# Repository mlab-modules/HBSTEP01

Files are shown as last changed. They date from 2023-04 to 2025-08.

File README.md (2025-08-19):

# HBSTEP01 - Stepper motor driver

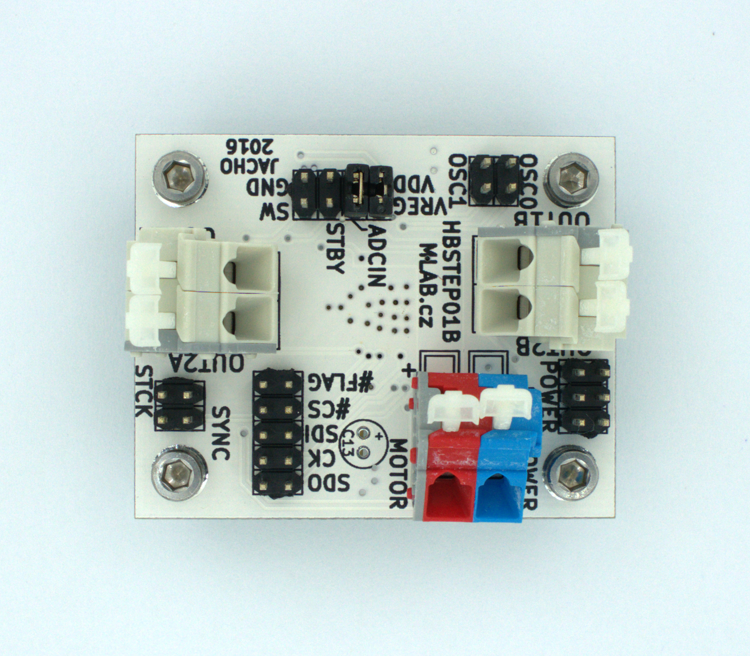
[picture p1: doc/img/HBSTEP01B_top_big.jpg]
HBSTEP01B


The HBSTEP01 is a bipolar stepper motor driver module built around the STMicroelectronics L6470 chip. It provides a complete microstepping motor control solution with SPI interface, allowing for precise motor control and advanced motion features.

## Features

* Microstepping up to 1/128 steps
* Operating voltage: 8 V to 45 V
* Maximum output current: 3 A RMS (7 A peak)
* Integrated non-dissipative current sensing
* Programmable speed profiles and position control
* Sensorless stall detection
* Built-in motion engine with acceleration/deceleration control
* Two levels of overtemperature protection
* Overcurrent and undervoltage protection
* SPI interface (5 Mbps max)

## Typical Applications

* Precision motorized stages
* Robotics
* 3D printers
* Industrial automation

## Electrical Specifications

| Parameter | Value |
| --- | --- |
| Supply Voltage (VS) | 8 V to 45 V  |
| Logic Voltage (VDD) | 3.3 V or 5 V |
| Max Output Current (RMS)  | 3 A |
| Max Output Current (Peak) | 7 A |
| SPI Clock Speed | up to 5 MHz  |

## Connectors and Interfaces

* **Motor Outputs**: 4 terminals for bipolar stepper motor
* **Power Supply**: VIN and GND (external 8–45 V supply)
* **Logic Interface**: SPI (SDI, SDO, CS, CK), STBY, SW, BUSY/SYNC, FLAG

## Control Interface

The module is controlled via SPI. The L6470 accepts a variety of commands:

* Motion commands: `Run`, `Move`, `GoTo`, etc.
* Positioning: absolute and relative
* Speed and acceleration profile programming

Refer to the [L6470 datasheet](https://www.st.com/resource/en/datasheet/l6470.pdf) for detailed command structure and register settings.

## Protections

* Overcurrent detection with programmable threshold
* Thermal warning and shutdown
* Undervoltage lockout
* Open-drain FLAG pin indicates fault conditions

## PCB Dimensions and Mounting

* Standard MLAB format
* Mounting holes compatible with other MLAB modules

## Resources

* [L6470 Datasheet (ST)](https://www.st.com/resource/en/datasheet/l6470.pdf)
* MLAB Wiki: [HBSTEP01](https://wiki.mlab.cz/doku.php?id=en:hbstep01)

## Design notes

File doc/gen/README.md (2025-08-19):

# PCB

Board size: 50.29x40.13 mm (1.98x1.58 inches)

- This is the size of the rectangle that contains the board
- Thickness: 1.6 mm (63 mils)
- Material: FR4
- Finish: HAL
- Layers: 2
- Copper thickness: 35 µm

Solder mask: TOP / BOTTOM

- Color: Green

Silk screen: TOP / BOTTOM

- Color: White

# Important sizes

Clearance: 0.25 mm (10 mils)

Track width: 0.25 mm (10 mils)

- By design rules: 0.25 mm (10 mils)

Drill: 0.75 mm (30 mils)

- Vias: 0.75 mm (30 mils) [Design: 0.6 mm (24 mils)]
- Pads: 0.9 mm (35 mils)
- The above values are real drill sizes, they add 0.1 mm (4 mils) to plated holes (PTH)

Via: 0.89/0.64 mm (35/25 mils)

- By design rules: 0.89/0.51 mm (35/20 mils)
- Micro via: yes [0.51/0.13 mm (20/5 mils)]
- Buried/blind via: yes
- Total: 46 (thru: 46 buried/blind: 0 micro: 0)

Outer Annular Ring: 0.07 mm (3 mils)

- By design rules: 0.26 mm (10 mils)

Eurocircuits class: 10A
- Using min drill 0.75 mm for an OAR of 0.07 mm

# General stats

Components count: (SMD/THT)

- Top: 0/30 (THT)
- Bottom: 25/1 (SMD + THT)

Defined tracks:

- 0.3 mm (12 mils)
- 0.4 mm (16 mils)
- 0.5 mm (20 mils)

Used tracks:

- 0.25 mm (10 mils) (126) defined: no
- 0.3 mm (12 mils) (145) defined: yes
- 0.4 mm (16 mils) (5) defined: yes
- 0.5 mm (20 mils) (39) defined: yes

Defined vias:

Used vias:

- 0.89/0.64 mm (35/25 mils) (Count: 46, Aspect: 1.8 A) defined: no

Holes (excluding vias):

- 0.8 mm (32 mils) (2)
- 0.89 mm (35 mils) (32)
- 1.3 mm (51 mils) (12)
- 3.0 mm (118 mils) (4)

Oval holes:

Drill tools (including vias and computing adjusts and rounding):

- 0.75 mm (30 mils) (46)
- 0.9 mm (35 mils) (2)
- 1.0 mm (39 mils) (32)
- 1.4 mm (55 mils) (12)
- 3.1 mm (122 mils) (4)

Solder paste stats:

Using a paste with 87.75 % alloy, that has an specific gravity for the alloy of 7.4 g/cm³
and 1.0 g/cm³ for the flux. This paste has an specific gravity of  4.15 g/cm³.

The stencil thickness is  0.12 mm.

| Side | Pads with paste | Area [mm²] | Paste [g] |
|---|---|---|---|
| Total  | 90 | 193.30 | 0.96 |

Note: this is just an approximation to the theoretical value. Margins of the solder mask and waste aren't computed.

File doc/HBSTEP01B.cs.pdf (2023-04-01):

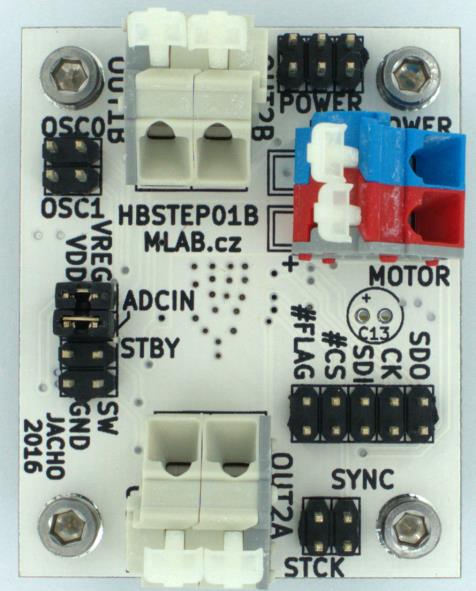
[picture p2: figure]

HBSTEP01B / 2017-04-13 / jacho / http://www.mlab.cz | 1 / 7
HBSTEP01B | MLAB

# HBSTEP01B – Budič krokových motorů

Jan Chroust

### Budič bipolárních krokových motorů s integrovaným obvodem L6470, který umožňuje mikrokrokování. Obvod umožňuje řízení

motorů v rozmezí 8 - 45 V a konstantním proudu 3 A (špičkově 7 A).

# 1. Technické parametry

Parametr | Hodnota | Poznámka
Napájení | 5V nebo 3,3V (interní regulátor 3V) | Napájení obvodu
Rozhraní | SPI
Integrovaný obvod | L6470
Spínací vlastnosti | 8 V - 45 V (3A - špičkově 7 A) | Dle spínaného napětí, je třeba volit kondenzátory s dostatečným provozním napětím
Mikrokrokování | Až 128 mikrokroků na krok
Rozměr | 40,1 x 50,6 x 16 mm

HBSTEP01B | MLAB

# 2. Popis konstrukce

## 2.1. Úvodem

Obvod se hodí pro řízení bipolárních krokových motorů v rozmezí 8 V - 45 V (tomuto napětí musí odpovídat provozní napětí kondenzátorů) a proudu 3 A (7 A špičkově). Tyto parametry jsou dosaženy bez přídavného chlazení. Komunikace probíhá přes rozhraní SPI. Velkou výhodou modulu je možnost mikrokrokování až do 128mikrokroků na jeden krok. Obvod obsahuje všechny základní ochrany (proudová, teplotní....). Kompletní vlastnosti obvodu je možné dohledat v dokumentaci obvodu L6470.

Pro připojení koncového spínače je určen na modulu pin SW, který je připojen k pinu integrovaného obvodu SW přes filtr (C14,R6). Vedle pinu SW je vyvedeno GND. Pin je ošetřen pull-up rezistorem, takže při nevyužití není potřeba žádného ošetření.

Pro napájení integrovaného obvodu z napájení krokového motoru (VSS) je potřeba umístit jumper mezi piny VREG a VDD. Interní regulátor generuje napětí 3V. V opačném případě je možné připojit externí napájení na hřebínek POWER IO (3,3V nebo 5V).

Pin ADCIN slouží jako zpětná vazba pro IO. Standardně stačí připojení pinu pomocí jumperu k děliči umístěném na PCB.

HBSTEP01B | MLAB

## 2.2. Zapojení modulu

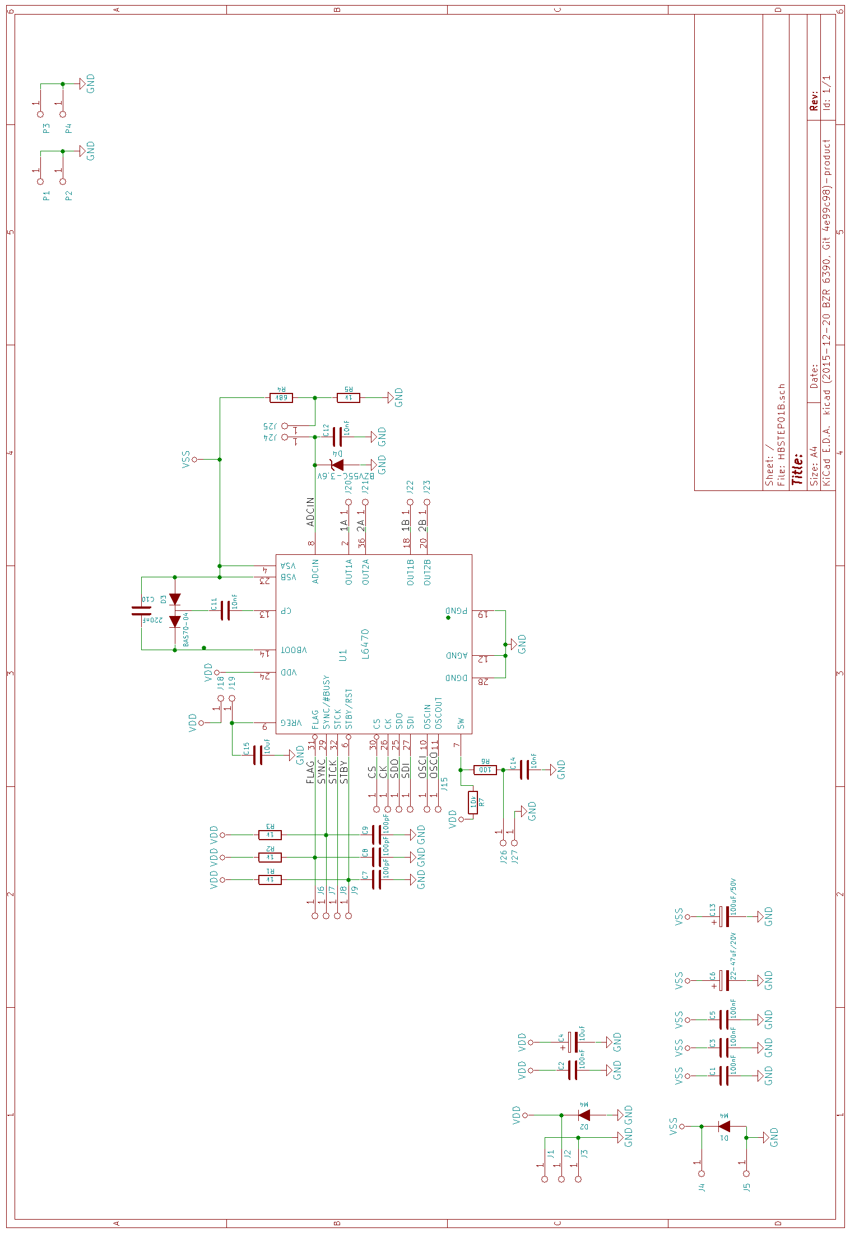
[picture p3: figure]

HBSTEP01B | MLAB

# 3. Osazení a oživení

## 3.1. Osazení

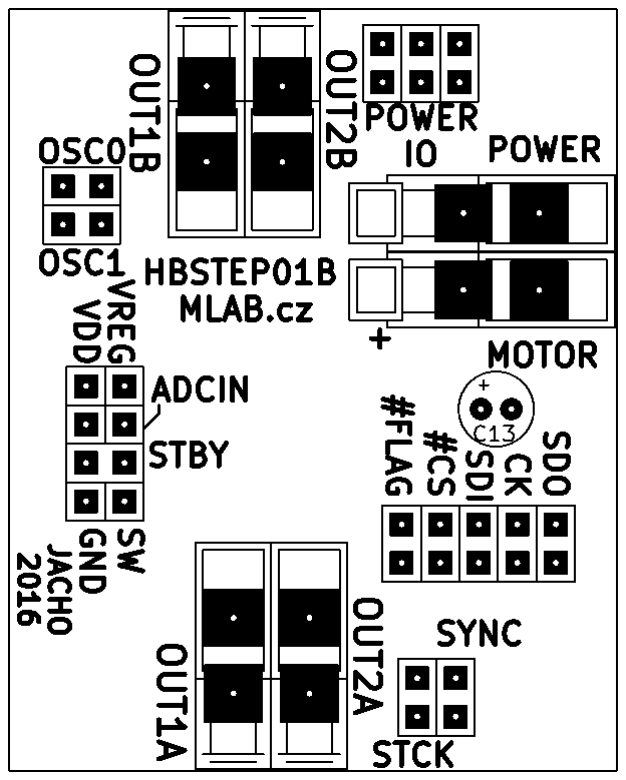
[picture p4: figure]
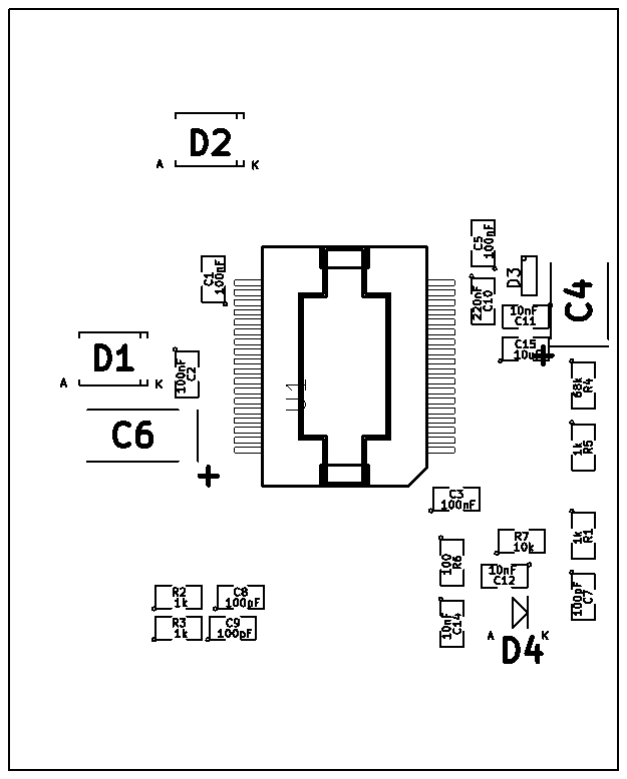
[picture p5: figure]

HBSTEP01B | MLAB

### 3.1.1. Seznam součástek

Označení | Typ | Pouzdro | Počet
J5,J4, J23,J22,J21,J20 | CONN1_1 | WAGO256 | 6
R5,R3,R2,R1 | 1k | SMD-0805 | 4
R4 | 68k | SMD-0805 | 1
P4,P3,P2,P1 | M3x12 | MountingHole_3mm | 4
J25,J24,J19,J18,J27,J26 | CONN1_1 | Straight_1x01 | 6
J15,J14,J13,J11,J10,J9,J8,J7,J6,J3,J2,J1,J12 | JUMP_2x1 | Straight_2x01 | 13
D4 | BZV55C-3,6V | MiniMELF_Standard | 1
D2,D1 | M4 | SMA_Standard | 2
C12,C11,C14 | 10nF | SMD-0805 | 3
C10 | 220nF | SMD-0805 | 1
C9,C8,C7 | 100pF | SMD-0805 | 3
C6 | 22-47uF/20V | TantalC_SizeC_Reflow | 1
C5,C3,C2,C1 | 100nF | SMD-0805 | 4
C4 | 10uF | TantalC_SizeB_Reflow | 1
U1 | L6470PD | POWERSO36 | 1
D3 | BAS70-04 | SOT-23 | 1
C13 | 100uF/50V | Elko_vert_11x5mm_RM2_CopperClear | 1
R6 | 100 | SMD-0805 | 1
R7 | 10k | SMD-0805 | 1
C15 | 10uF/10V | SMD-0805 | 1

Jumper: VREG – VDD, ADCIN

## 3.2. Oživení

Po osazení je dobré zkontrolovat, zda se nenacházejí na modulu žádné zkraty. Po propojení pomocí jumperu není dále potřeba nic oživovat.

HBSTEP01B | MLAB

# 4. Vzorový program a otestování

Vzorový program využívá pythonu a knihovny PyMLAB, který je ke stažení na Githubu.

Data ke stažení na: https://github.com/MLAB-project/pymlab

Návod na instalaci PyMLAB: | http://wiki.mlab.cz/doku.php?id=cs:pymlab
| https://pypi.python.org/pypi/pymlab/0.2

Vzorový kód se nachází v svn ve složce modulu: I2CSPI_HBSTEP_SX17_test.py

Vzorový program počítá s motorem SX17-1003LQEF

Parametry vkládané do programu 0 10 50

Pro otestování pomocí vzorového programu je zapotřebí modulu USBI2C01A, I2CSPI01A a 12 V zdroj.

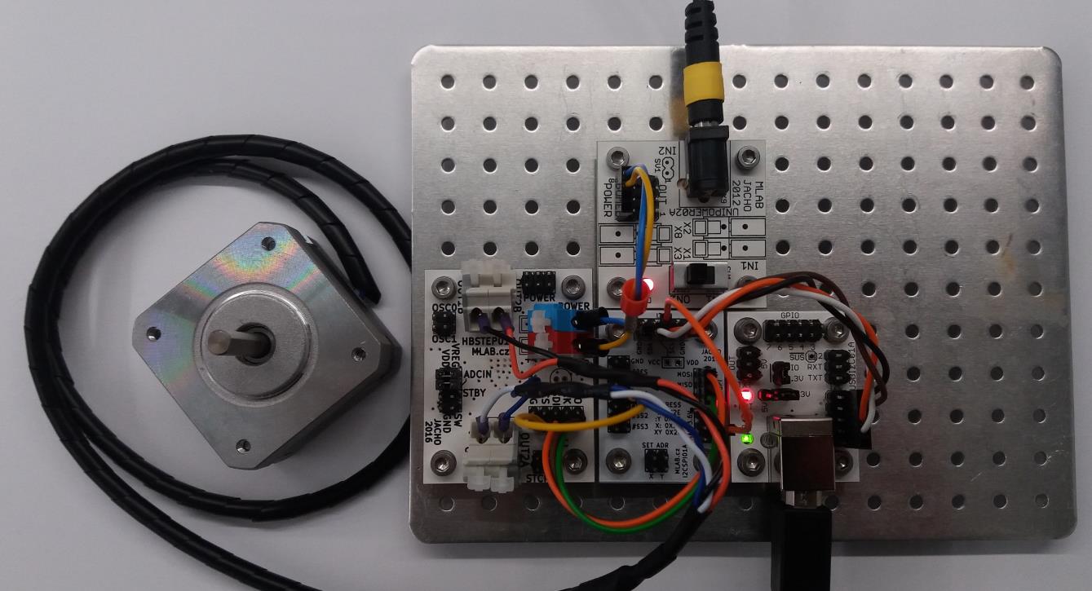
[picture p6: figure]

Modul HBSTEP01B je napájen 12V přes modul UNIPOWER02A. Modul I2CSPI01A je napájen 3,3 V z modulu USBI2C01A.

HBSTEP01B | MLAB

Propojení:

USBI2C01A-I2CSPI01A – I2C kabel standardu MLAB

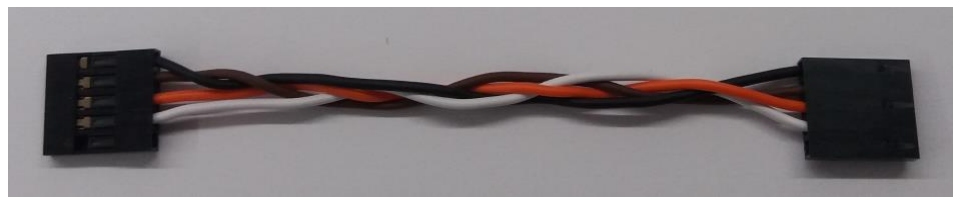
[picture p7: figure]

SDA – bílá

SCL – hnědá

3V3 – oranžová

GND – černá

I2CSPI01A

Oranžový vodič mezi VCC (I2C hřebínek) a VDD (napájecí hřebínek modulu)

I2CSPI - HBSTEP

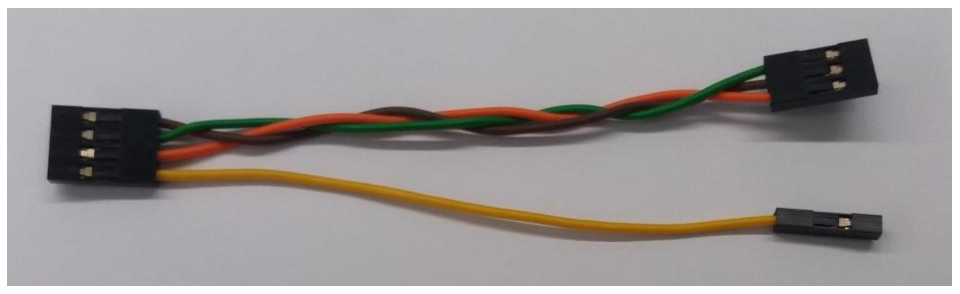
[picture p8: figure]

HBSTEP01B – I2CSPI01A

CS – SS0 – žlutá

SDI – MOSI – oranžová

SDO – MISO - hnědá

CK-CLK – zelená

sdo-miso - hneda

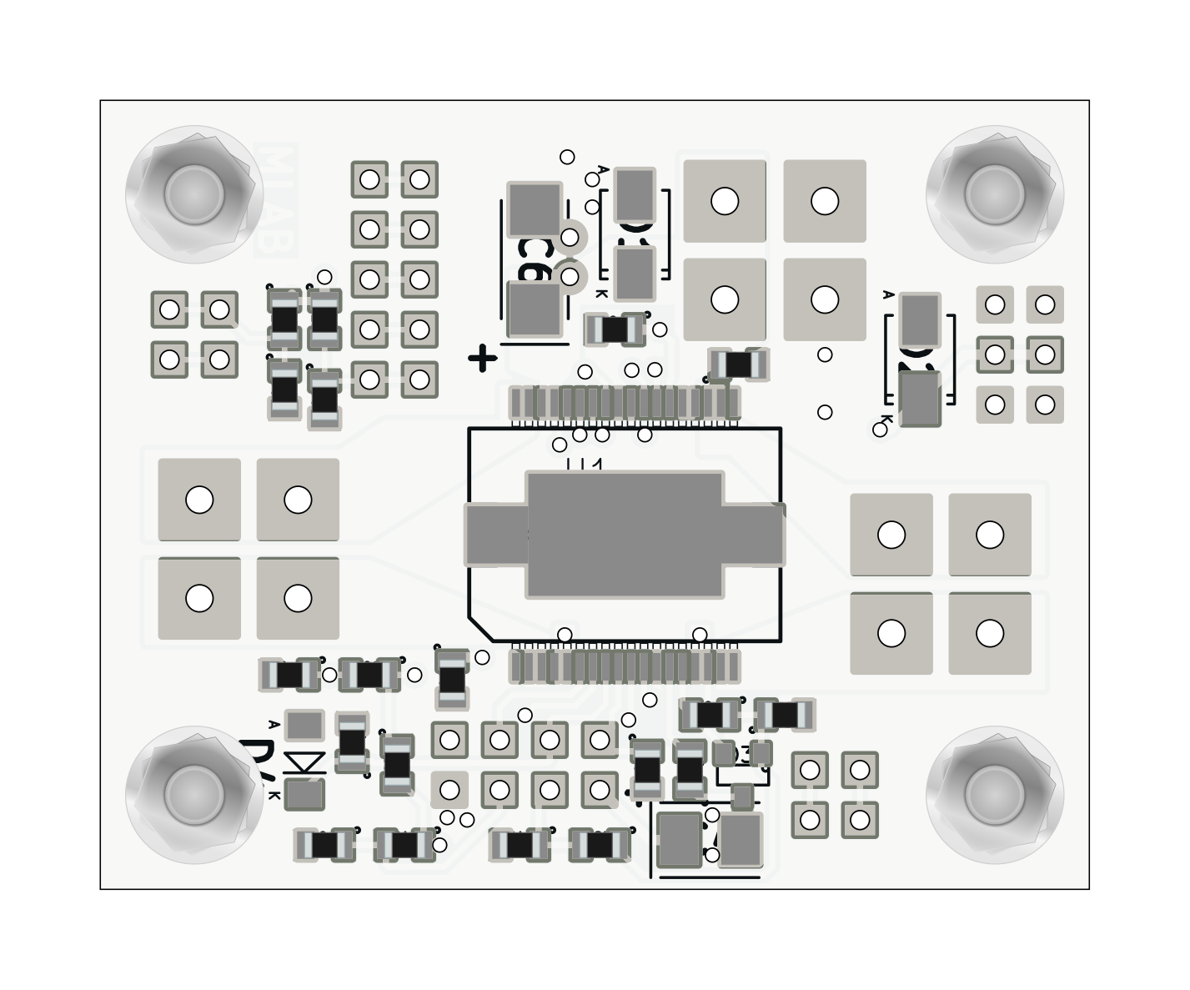
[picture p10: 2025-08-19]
doc/gen/img/HBSTEP01-bottom.png

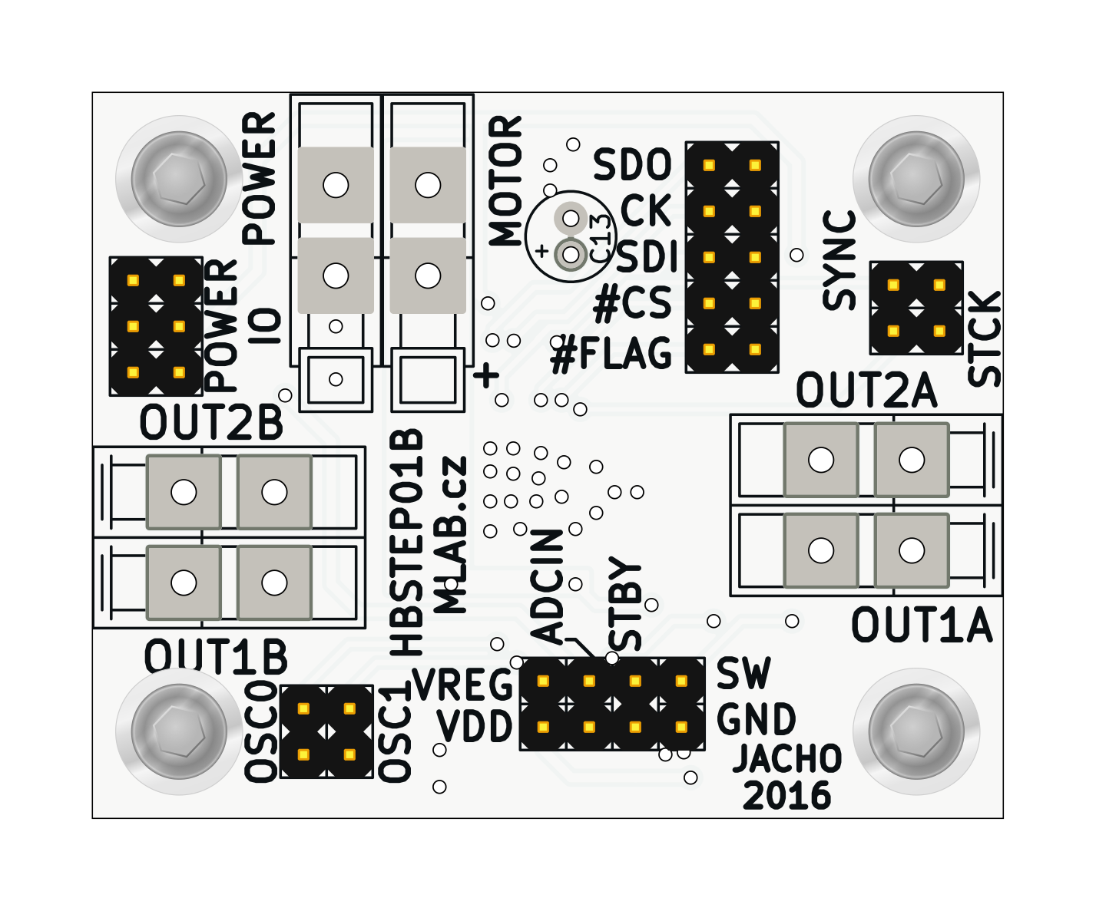
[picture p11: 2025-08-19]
doc/gen/img/HBSTEP01-top.png

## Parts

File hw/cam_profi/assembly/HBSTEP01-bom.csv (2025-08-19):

Component | Description | Part | References | Value | Footprint | Quantity Per PCB | Datasheet
1 |  | C_13 | C7 | 100pF | SMD-0805 | 1
2 |  | C_14 | C8 | 100pF | SMD-0805 | 1
3 |  | C_15 | C9 | 100pF | SMD-0805 | 1
4 |  | C_17 | C11 | 10nF | SMD-0805 | 1
5 |  | C_23 | C12 | 10nF | SMD-0805 | 1
6 |  | C_18 | C14 | 10nF | SMD-0805 | 1
7 |  | C_21 | C1 | 100nF | SMD-0805 | 1
8 |  | C_24 | C2 | 100nF | SMD-0805 | 1
9 |  | C_19 | C3 | 100nF | SMD-0805 | 1
10 |  | C_20 | C5 | 100nF | SMD-0805 | 1
11 |  | C_16 | C10 | 220nF | SMD-0805 | 1
12 |  | C_22 | C15 | 10uF | SMD-0805 | 1
13 |  | CP2_6 | C4 | 10uF | TantalC_SizeB_Reflow | 1
14 |  | CP2_5 | C13 | 100uF/50V | Elko_vert_11x5mm_RM2_CopperClear | 1
15 |  | CP2_4 | C6 | 22-47uF/20V | TantalC_SizeC_Reflow | 1
16 |  | BAT46SW_2 | D3 | BAS70-04 | SOT-23 | 1
17 |  | D_ZENER_2 | D4 | BZV55C-3,6V |  | 1
18 |  | DIODE_3 | D1 | M4 | SMA_Standard | 1
19 |  | DIODE_4 | D2 | M4 | SMA_Standard | 1
20 |  | CONN1_1_22 | J18 | CONN1_1 | Straight_1x01 | 1
21 |  | CONN1_1_21 | J19 | CONN1_1 | Straight_1x01 | 1
22 |  | CONN1_1_17 | J20 | CONN1_1 | WAGO256_2 | 1
23 |  | CONN1_1_18 | J21 | CONN1_1 | WAGO256_2 | 1
24 |  | CONN1_1_19 | J22 | CONN1_1 | WAGO256_2 | 1
25 |  | CONN1_1_20 | J23 | CONN1_1 | WAGO256_2 | 1
26 |  | CONN1_1_15 | J24 | CONN1_1 | Straight_1x01 | 1
27 |  | CONN1_1_16 | J25 | CONN1_1 | Straight_1x01 | 1
28 |  | CONN1_1_13 | J26 | CONN1_1 | Straight_1x01 | 1
29 |  | CONN1_1_14 | J27 | CONN1_1 | Straight_1x01 | 1
30 |  | CONN1_1_23 | J4 | CONN1_1 | WAGO256 | 1
31 |  | CONN1_1_24 | J5 | CONN1_1 | WAGO256 | 1
32 |  | JUMP_2x1_24 | J1 | JUMP_2x1 | Straight_2x01 | 1
33 |  | JUMP_2x1_22 | J10 | JUMP_2x1 | Straight_2x01 | 1
34 |  | JUMP_2x1_23 | J11 | JUMP_2x1 | Straight_2x01 | 1
35 |  | JUMP_2x1_21 | J12 | JUMP_2x1 | Straight_2x01 | 1
36 |  | JUMP_2x1_14 | J13 | JUMP_2x1 | Straight_2x01 | 1
37 |  | JUMP_2x1_15 | J14 | JUMP_2x1 | Straight_2x01 | 1
38 |  | JUMP_2x1_16 | J15 | JUMP_2x1 | Straight_2x01 | 1
39 |  | JUMP_2x1_25 | J2 | JUMP_2x1 | Straight_2x01 | 1
40 |  | JUMP_2x1_26 | J3 | JUMP_2x1 | Straight_2x01 | 1
41 |  | JUMP_2x1_20 | J6 | JUMP_2x1 | Straight_2x01 | 1
42 |  | JUMP_2x1_19 | J7 | JUMP_2x1 | Straight_2x01 | 1
43 |  | JUMP_2x1_18 | J8 | JUMP_2x1 | Straight_2x01 | 1
44 |  | JUMP_2x1_17 | J9 | JUMP_2x1 | Straight_2x01 | 1
45 |  | R_9 | R6 | 100 | SMD-0805 | 1
46 |  | R_12 | R1 | 1k | SMD-0805 | 1
47 |  | R_11 | R2 | 1k | SMD-0805 | 1
48 |  | R_10 | R3 | 1k | SMD-0805 | 1
49 |  | R_14 | R5 | 1k | SMD-0805 | 1
50 |  | R_8 | R7 | 10k | SMD-0805 | 1
51 |  | R_13 | R4 | 68k | SMD-0805 | 1
52 |  | L6470_2 | U1 | L6470 | POWERSO36 | 1

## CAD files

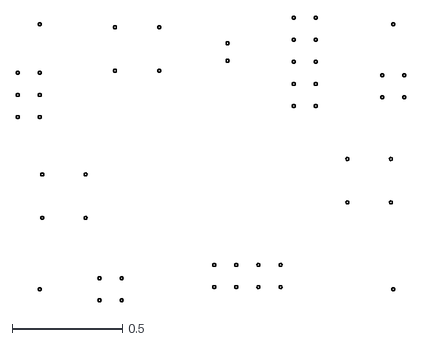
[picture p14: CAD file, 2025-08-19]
doc/gen/dxf/HBSTEP01-User_Eco1.dxf
1.76 x 1.29

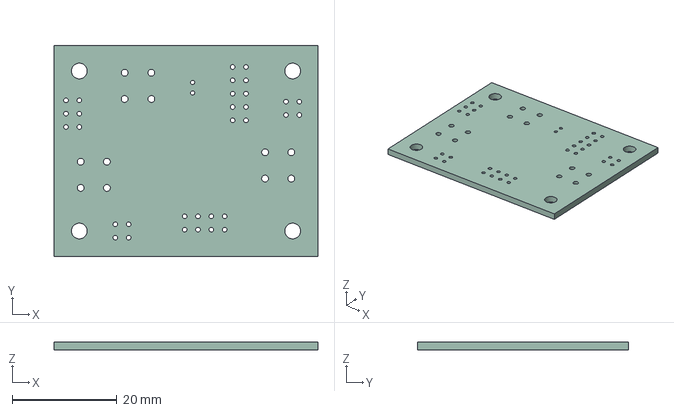
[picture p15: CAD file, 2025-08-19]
doc/gen/HBSTEP01.step
50.3 x 40.1 x 1.51 mm

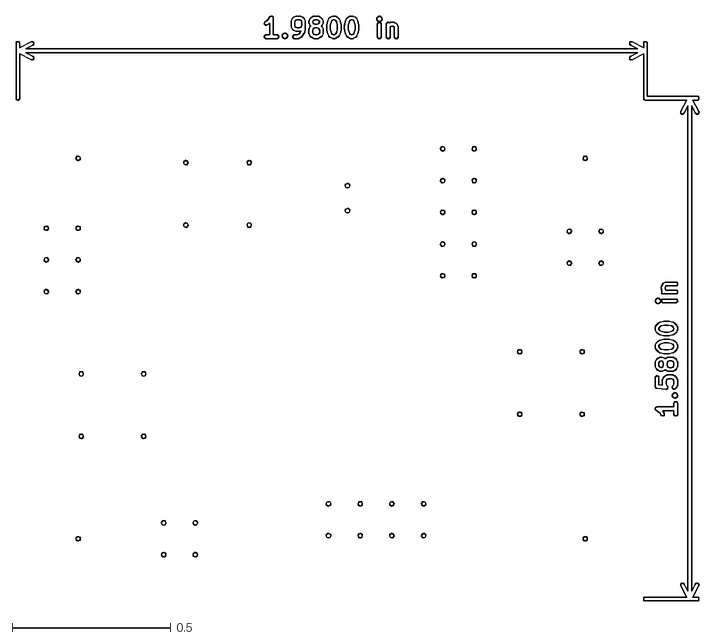
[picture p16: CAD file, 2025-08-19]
doc/gen/dxf/HBSTEP01-User_Drawings.dxf
2.15 x 1.85

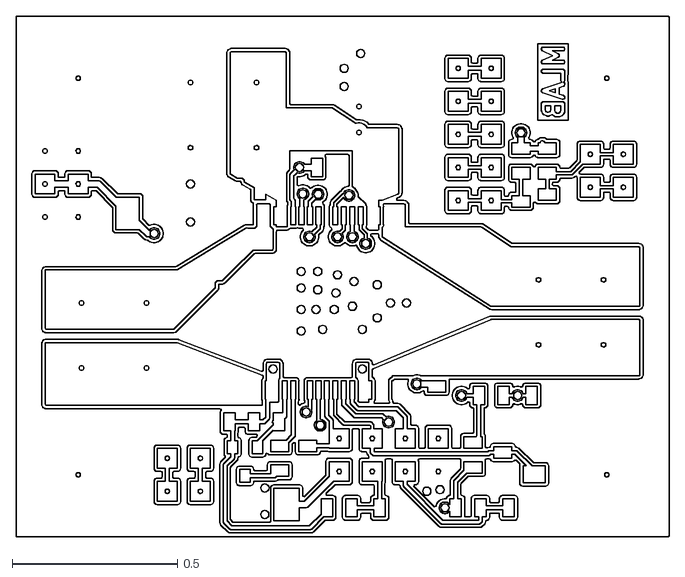
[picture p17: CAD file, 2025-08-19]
doc/gen/dxf/HBSTEP01-B_Cu.dxf
1.98 x 1.58

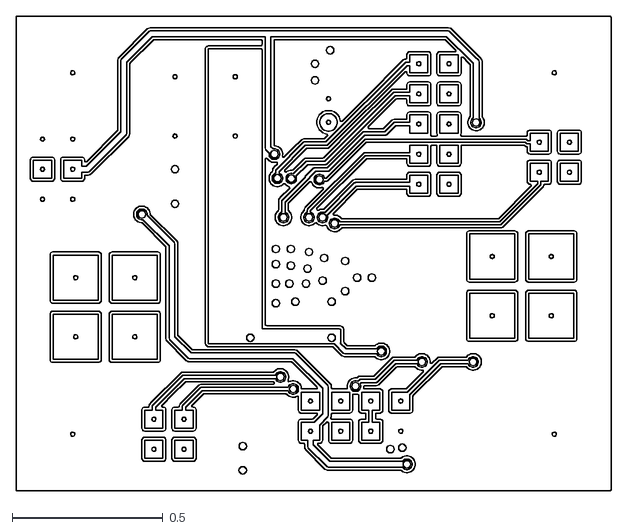
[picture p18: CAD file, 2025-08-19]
doc/gen/dxf/HBSTEP01-F_Cu.dxf
1.98 x 1.58

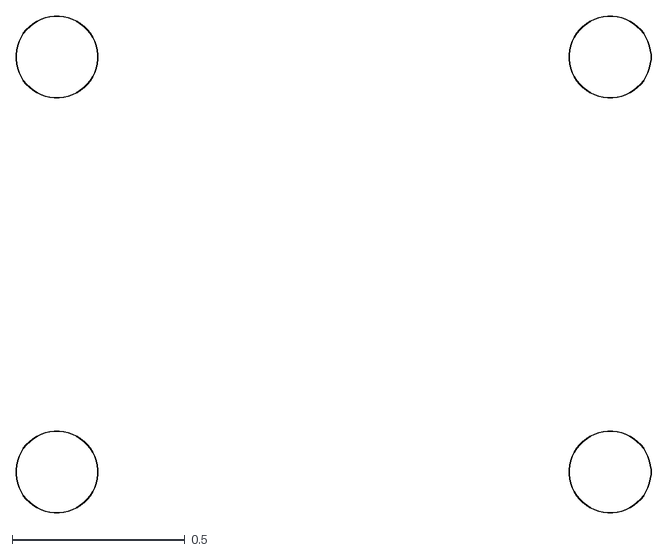
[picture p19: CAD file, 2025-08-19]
doc/gen/dxf/HBSTEP01-F_Adhesive.dxf
1.84 x 1.44

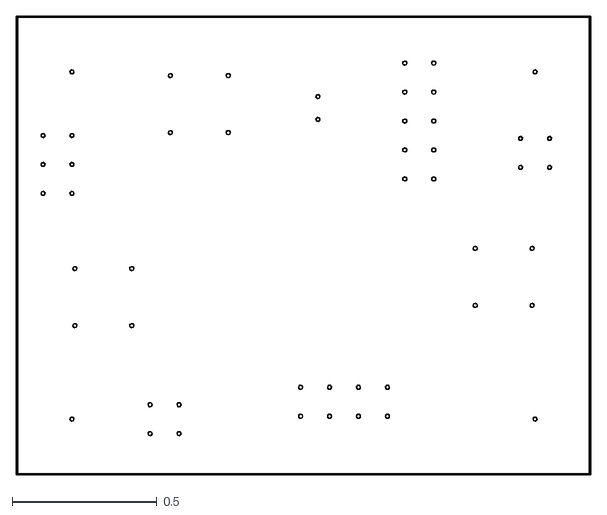
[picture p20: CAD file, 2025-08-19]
doc/gen/dxf/HBSTEP01-Edge_Cuts.dxf
1.98 x 1.58

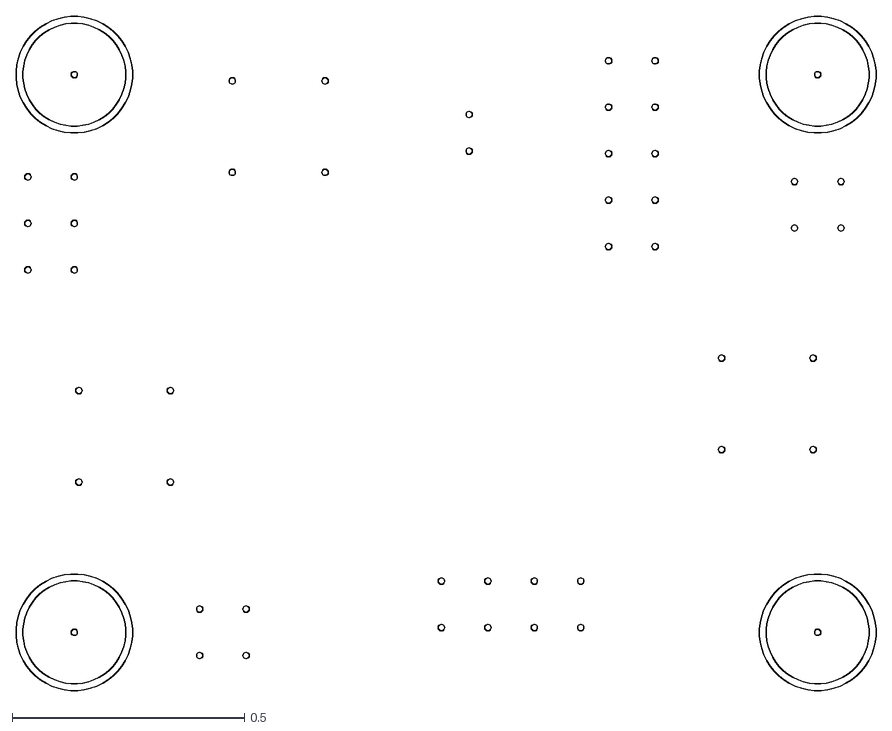
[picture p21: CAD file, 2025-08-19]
doc/gen/dxf/HBSTEP01-User_Comments.dxf
1.85 x 1.45

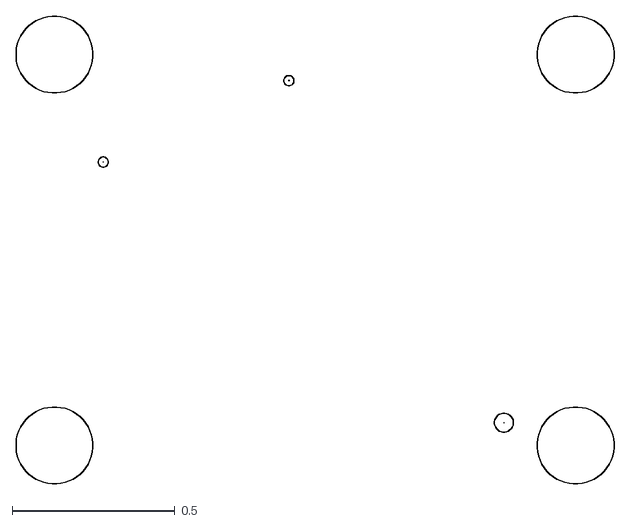
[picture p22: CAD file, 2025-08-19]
doc/gen/dxf/HBSTEP01-B_Adhesive.dxf
1.84 x 1.44

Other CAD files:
doc/gen/dxf/HBSTEP01-B_Mask.dxf
doc/gen/dxf/HBSTEP01-B_Paste.dxf
doc/gen/dxf/HBSTEP01-B_Silkscreen.dxf
doc/gen/dxf/HBSTEP01-F_Mask.dxf
doc/gen/dxf/HBSTEP01-F_Paste.dxf
doc/gen/dxf/HBSTEP01-F_Silkscreen.dxf

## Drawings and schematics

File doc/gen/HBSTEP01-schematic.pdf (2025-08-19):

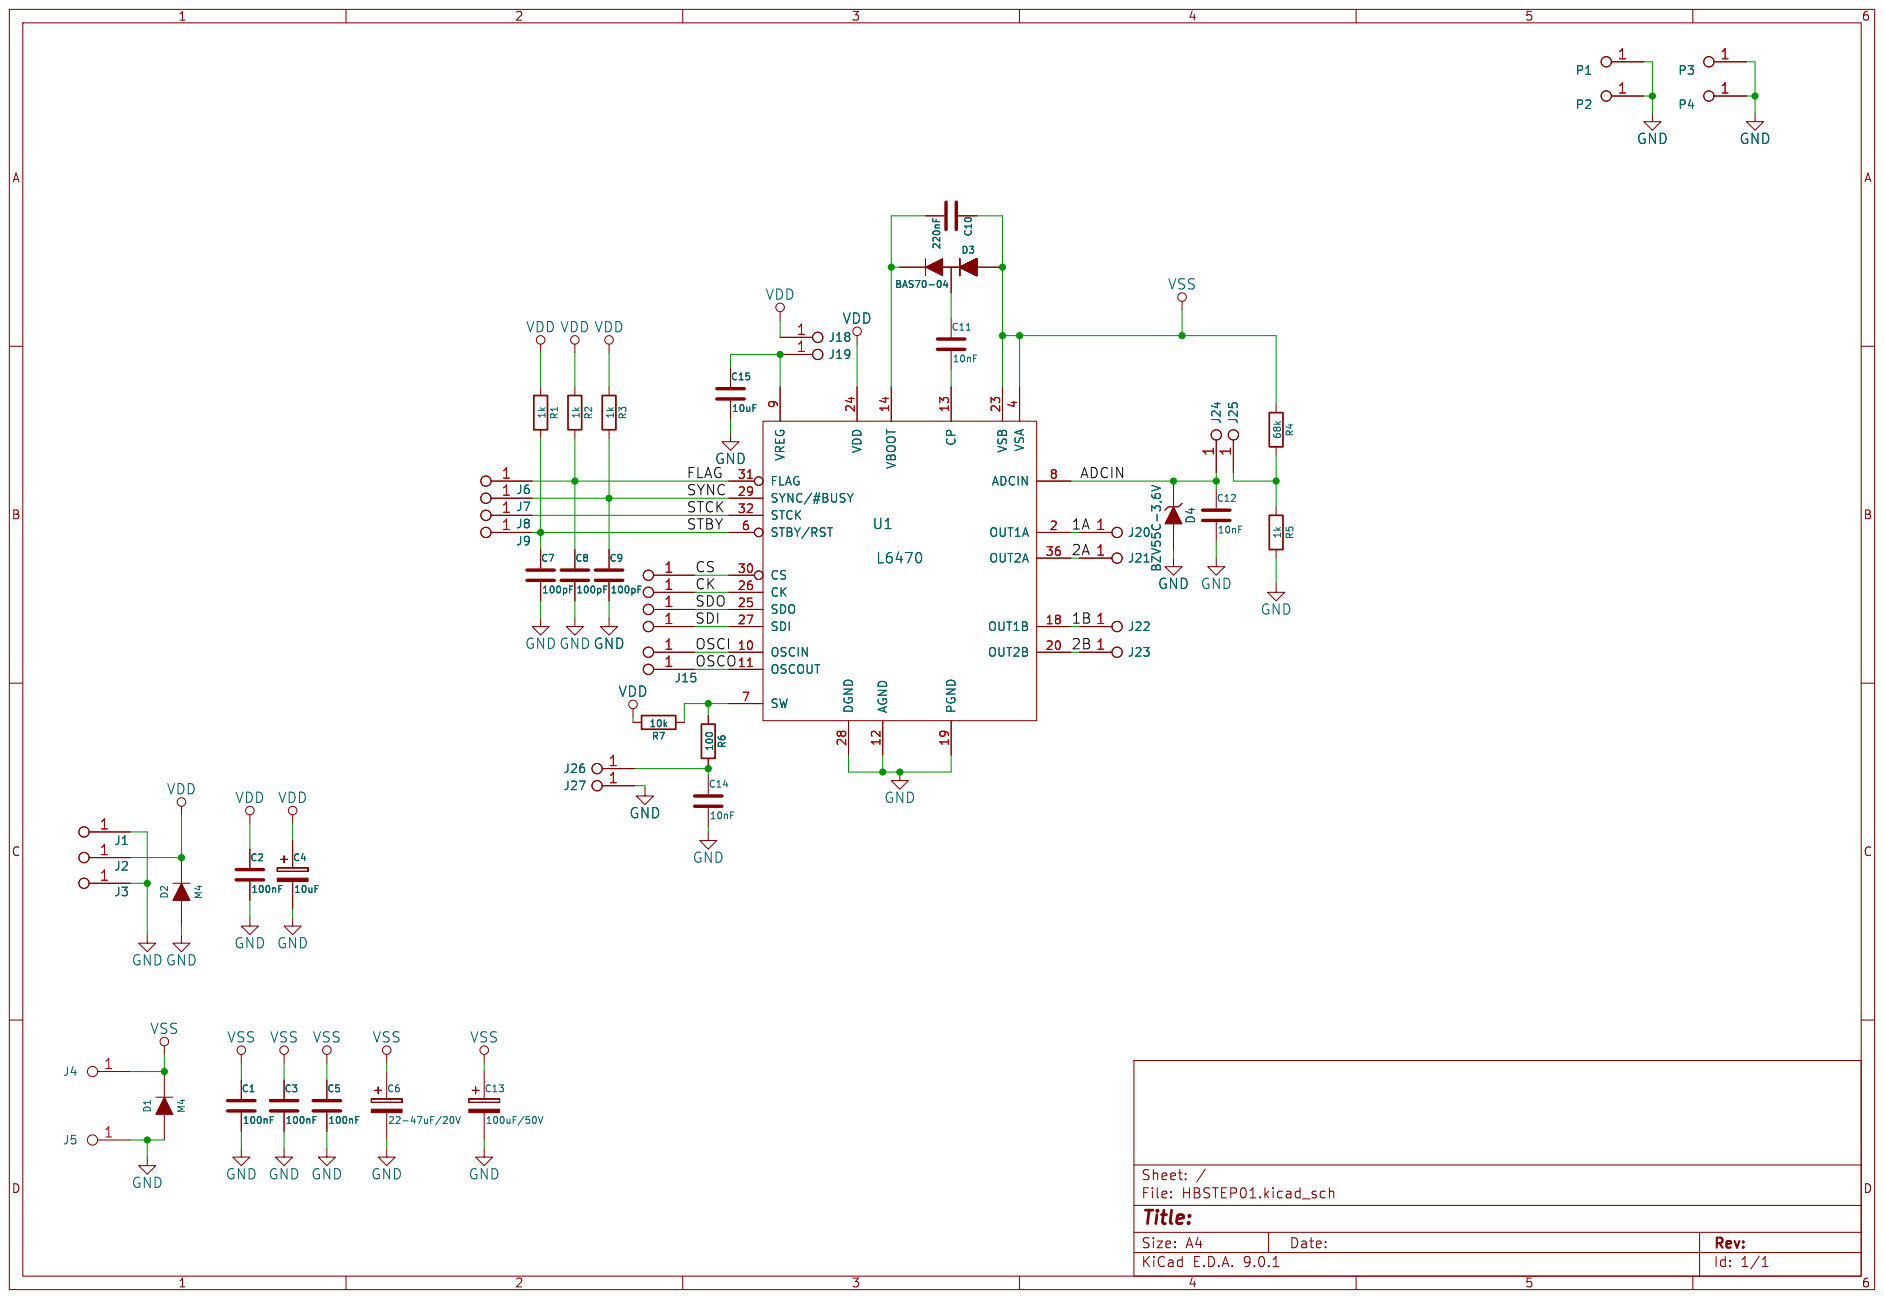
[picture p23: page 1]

9 DGND 28 VDD 24 AGND 12 VBOOT 14 CP 13 PGND 19 VSB 23 VSA

Id: 1/1 Title: File: HBSTEP01.kicad_sch Sheet: /

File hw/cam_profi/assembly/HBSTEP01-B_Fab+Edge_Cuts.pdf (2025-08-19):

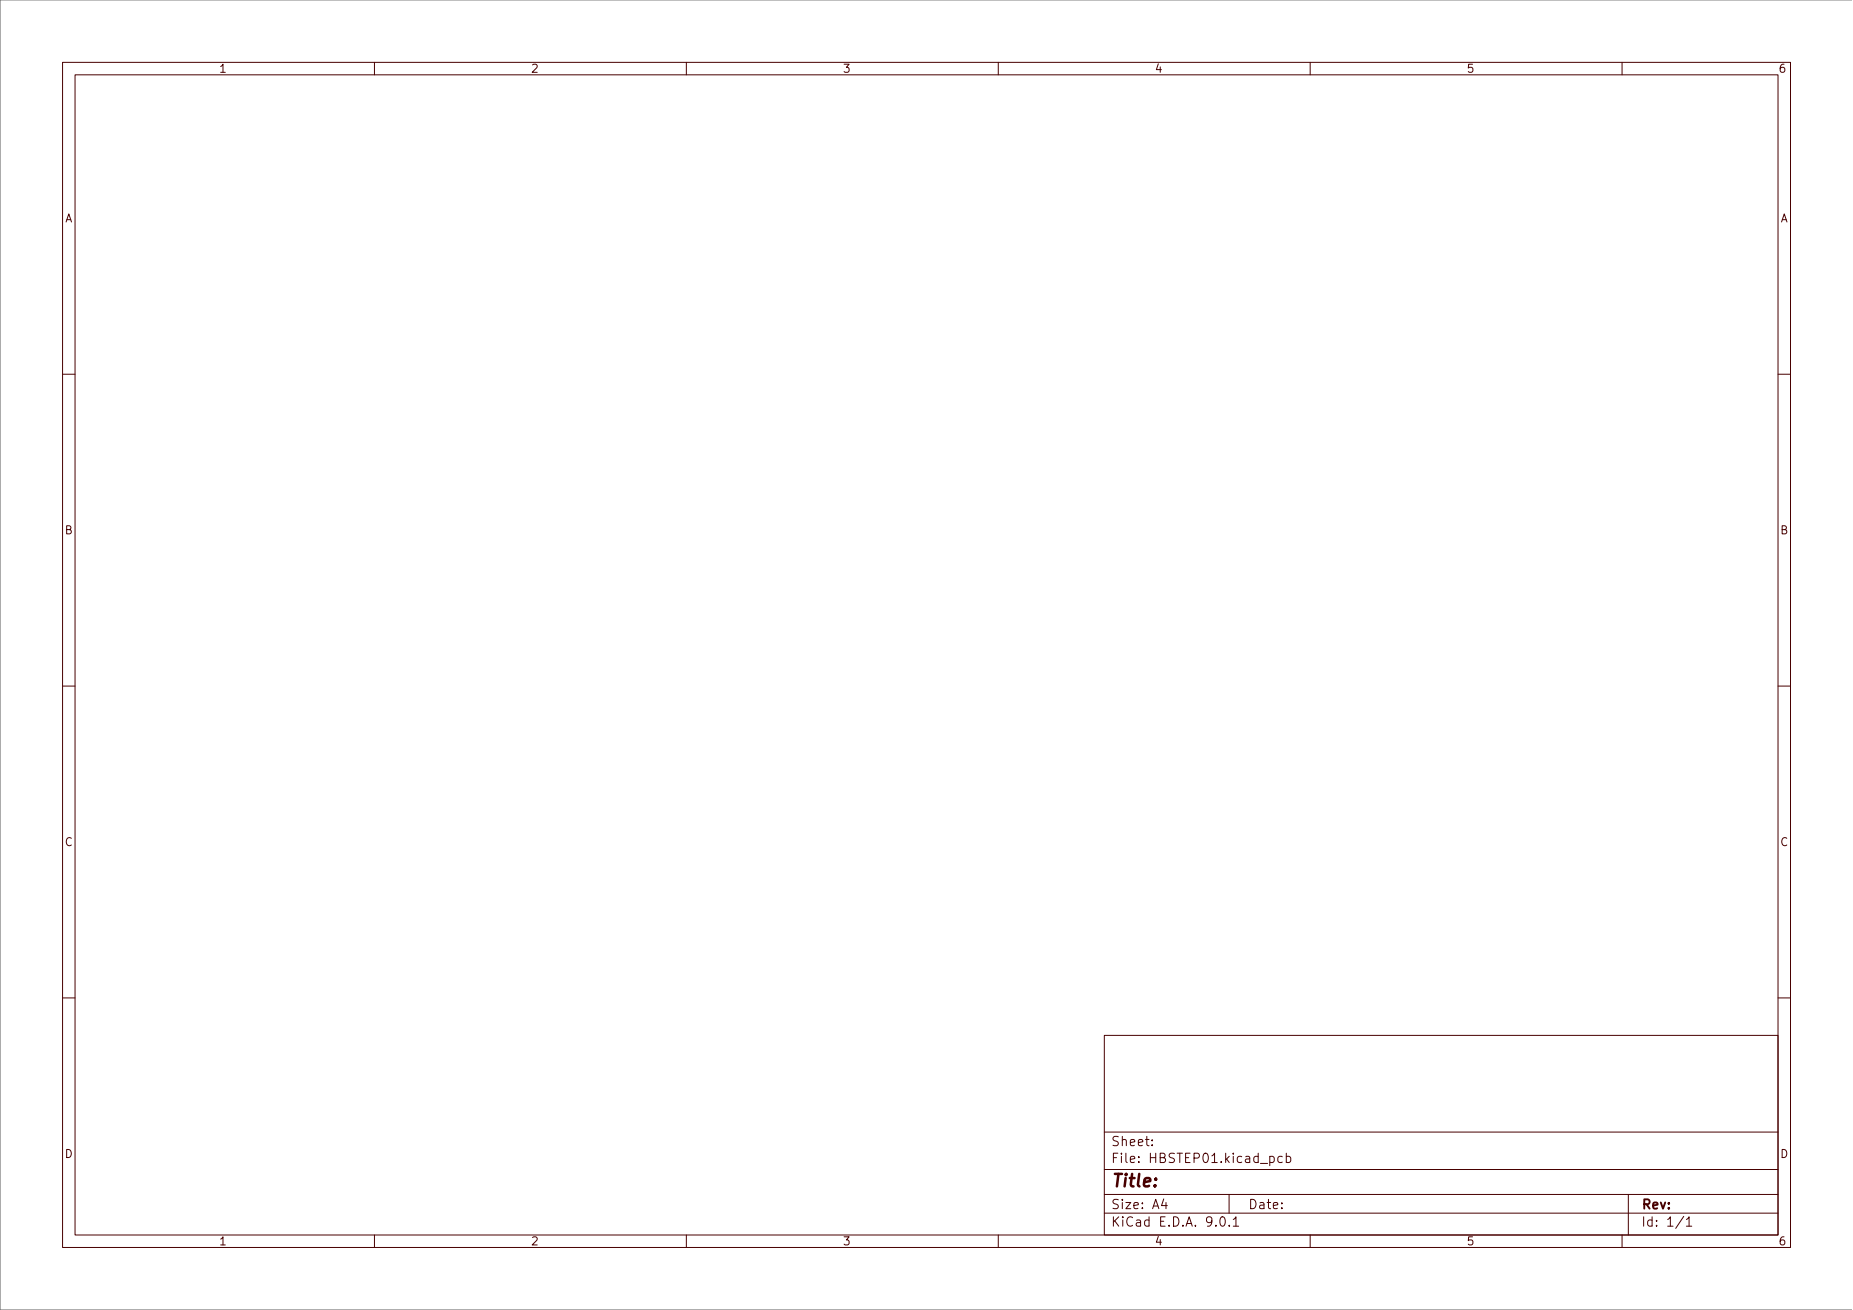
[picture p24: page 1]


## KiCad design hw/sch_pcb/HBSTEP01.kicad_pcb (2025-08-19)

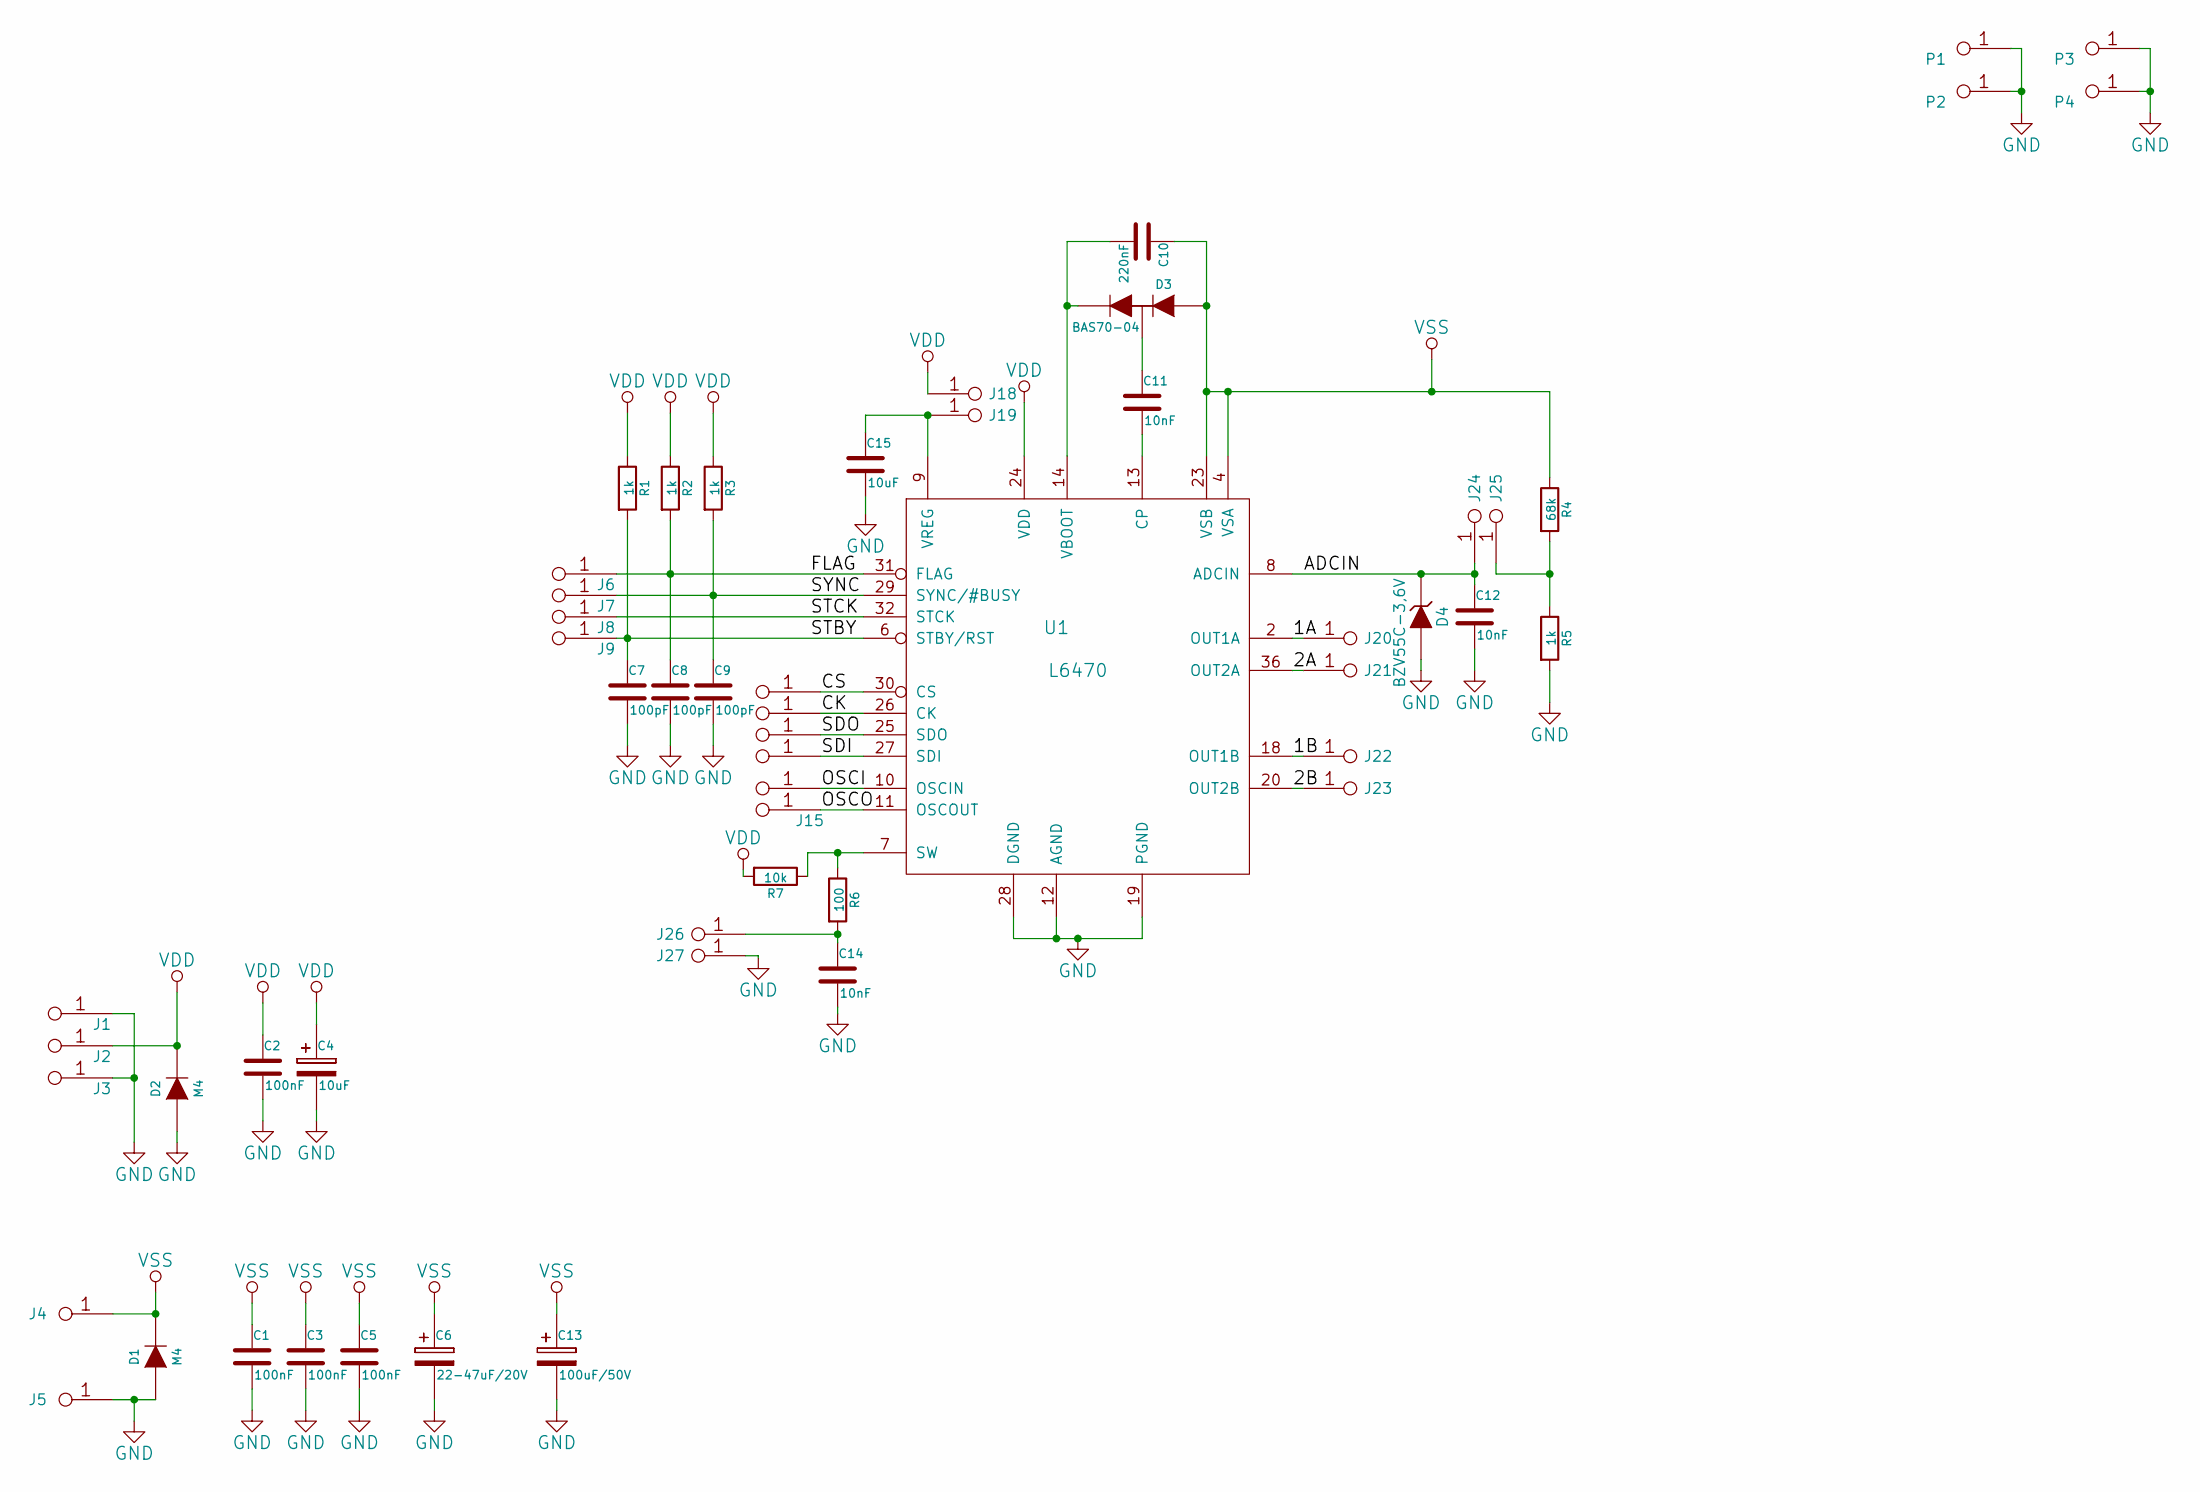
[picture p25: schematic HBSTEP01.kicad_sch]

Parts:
C1, C2, C3, C5: 100nF; SMD-0805
C4: 10uF; TantalC_SizeB_Reflow
C6: 22-47uF/20V; TantalC_SizeC_Reflow
C7, C8, C9: 100pF; SMD-0805
C10: 220nF; SMD-0805
C11, C12, C14: 10nF; SMD-0805
C13: 100uF/50V; Elko_vert_11x5mm_RM2_CopperClear
C15: 10uF; SMD-0805
D1, D2: M4; SMA_Standard
D3: BAS70-04; SOT-23
D4: BZV55C-3,6V
J1, J2, J3, J6, J7, J8, J9, J10, J11, J12, J13, J14, J15: JUMP_2x1; Straight_2x01
J4, J5: CONN1_1; WAGO256
J18, J19, J24, J25, J26, J27: CONN1_1; Straight_1x01
J20, J21, J22, J23: CONN1_1; WAGO256_2
P1, P2, P3, P4: sroub; MountingHole_3mm
R1, R2, R3, R5: 1k; SMD-0805
R4: 68k; SMD-0805
R6: 100; SMD-0805
R7: 10k; SMD-0805
U1: L6470; POWERSO36

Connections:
/1A: J20.1, U1.2 (OUT1A), U1.3 (OUT1A)
/1B: J22.1, U1.17 (OUT1B), U1.18 (OUT1B)
/2A: J21.1, U1.35 (OUT2A), U1.36 (OUT2A)
/2B: J23.1, U1.20 (OUT2B), U1.21 (OUT2B)
/ADCIN: C12.1, D4.2 (K), J24.1, U1.8 (ADCIN)
/CK: J11.1, J11.2, U1.26 (CK)
/CS: J10.1, J10.2, U1.30 (CS)
/FLAG: C8.1, J6.1, J6.2, R2.2, U1.31 (FLAG)
/OSCI: J14.1, J14.2, U1.10 (OSCIN)
/OSCO: J15.1, J15.2, U1.11 (OSCOUT)
/SDI: J13.1, J13.2, U1.27 (SDI)
/SDO: J12.1, J12.2, U1.25 (SDO)
/STBY: C7.1, J9.1, J9.2, R1.2, U1.6 (STBY/RST)
/STCK: J8.1, J8.2, U1.32 (STCK)
/SYNC: C9.1, J7.1, J7.2, R3.2, U1.29 (SYNC/#BUSY)
GND: C1.2, C2.2, C3.2, C4.2, C5.2, C6.2, C7.2, C8.2, C9.2, C12.2, C13.2, C14.2, C15.2, D1.1 (A), D2.1 (A), D4.1 (A), J1.1, J1.2, J3.1, J3.2, J5.1, J27.1, P1.1, P2.1, P3.1, P4.1, R5.2, U1.1 (PGND), U1.12 (AGND), U1.19 (PGND), U1.28 (DGND), U1.50 (PGND), U1.51 (PGND), U1.52 (PGND)
unnamed: C10.2, D3.2 (A), U1.14 (VBOOT)
unnamed: C11.1, D3.3 (m)
unnamed: C11.2, U1.13 (CP)
unnamed: C14.1, J26.1, R6.2
unnamed: C15.1, J19.1, U1.9 (VREG)
unnamed: J25.1, R4.2, R5.1
unnamed: R6.1, R7.1, U1.7 (SW)
VDD: C2.1, C4.1, D2.2 (K), J2.1, J2.2, J18.1, R1.1, R2.1, R3.1, R7.2, U1.24 (VDD)
VSS: C1.1, C3.1, C5.1, C6.1, C10.1, C13.1, D1.2 (K), D3.1 (A), J4.1, R4.1, U1.4 (VSA), U1.5 (VSA), U1.15 (VSB), U1.16 (VSB), U1.22 (VSB), U1.23 (VSB), U1.33 (VSA), U1.34 (VSA)

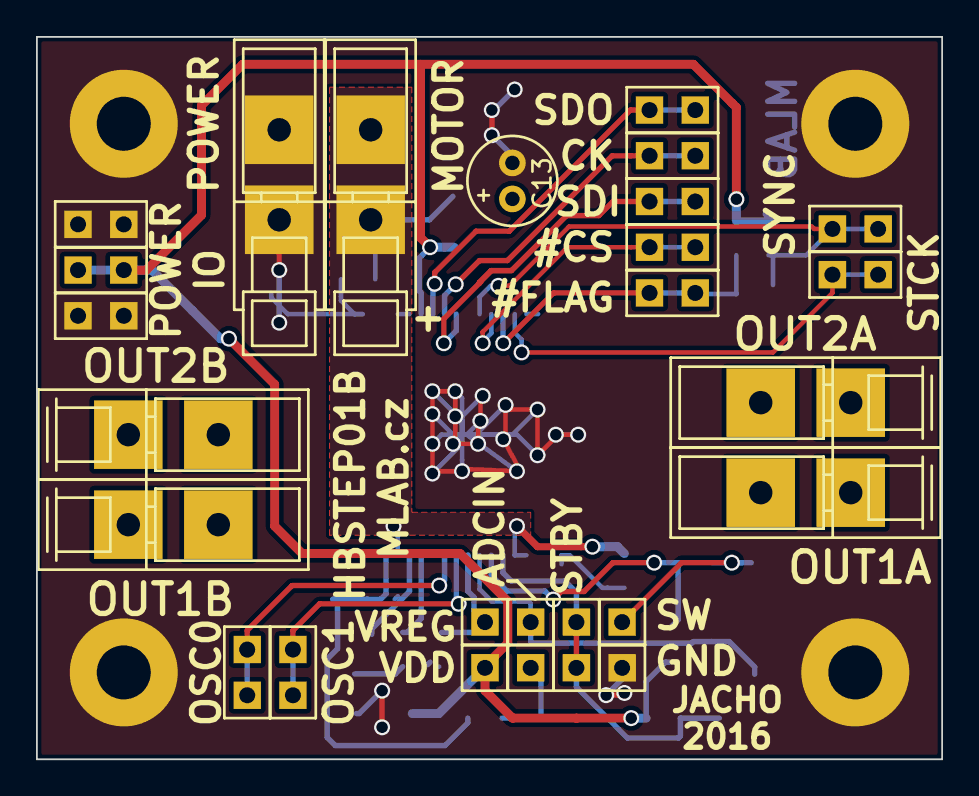
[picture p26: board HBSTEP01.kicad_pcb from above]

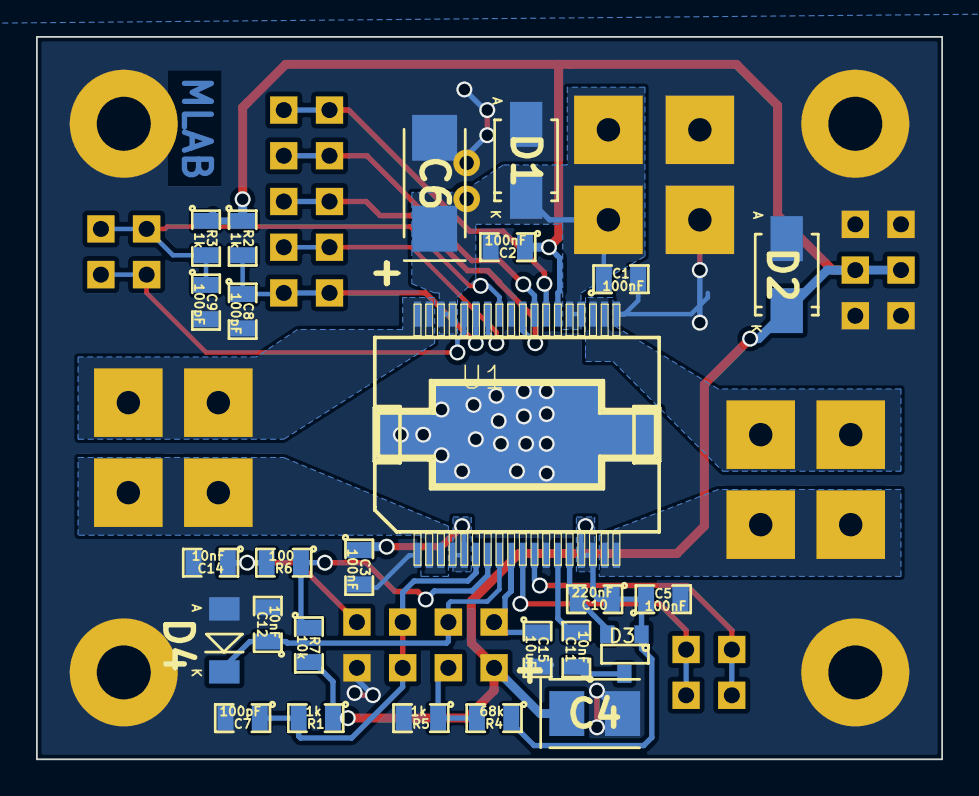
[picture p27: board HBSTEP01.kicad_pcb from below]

Board: 2 copper layers, 50.3 x 40.1 mm, 56 parts (26 on the bottom side), 25 nets.

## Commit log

2023-04-01 Adding force option to enable splitting in not fresh copy of Modules repository.
    [HBSTEP01B-B.Cu.gbr, HBSTEP01B-B.Mask.gbr, HBSTEP01B-Edge.Cuts.gbr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]
2025-08-19 Update project to KiCAD9.
    [HBSTEP01B.kicad_pcb, HBSTEP01B.kicad_sch]
2025-08-19 Cleanup KiCAD project.
    [HBSTEP01.kicad_pcb, HBSTEP01.kicad_sch, HBSTEP01B.sch]
2025-08-19 Update actions products
    [HBSTEP01-B_Adhesive.dxf, HBSTEP01-B_Courtyard.dxf, HBSTEP01-B_Cu.dxf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]
